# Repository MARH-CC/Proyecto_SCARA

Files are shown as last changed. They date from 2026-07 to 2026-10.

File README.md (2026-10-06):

# Proyecto SCARA – Universidad Militar Nueva Granada

Este repositorio contiene el desarrollo completo de un robot manipulador tipo **SCARA**, desde el diseño mecánico en SolidWorks hasta su modelado cinemático, su simulación en Matlab, su descripción en formato URDF y la sintonización del control de posición de sus servomotores. El objetivo del proyecto es diseñar, modelar y simular un brazo SCARA accionado por servomotores y una articulación prismática que permita una implementación precisa.

El robot tiene **3 grados de libertad**: dos articulaciones rotacionales ($\theta_1$, $\theta_2$) y una prismática ($d_3$).

## Estructura del repositorio

| Carpeta | Contenido |
|---|---|
| [`1. Piezas y Ensambles SolidWorks`](./1.%20Piezas%20y%20Ensambles%20SolidWorks) | Piezas individuales (`.SLDPRT`) y ensamblajes (`.SLDASM`) del robot en SolidWorks, con y sin servomotor. |
| [`2. Planos`](./2.%20Planos) | Planos técnicos (`.SLDDRW`) de las piezas y del ensamblaje general, más su versión en PDF. |
| [`3.Cinematica_Directa`](./3.Cinematica_Directa) | Desarrollo y cálculo de la cinemática directa del robot, resuelta por dos métodos independientes (Matrices de Transformación Homogénea y Denavit–Hartenberg) que se contrastan entre sí. |
| [`4.Cinematica_Inversa`](./4.Cinematica_Inversa) | Desarrollo y cálculo de la cinemática inversa del robot mediante desacoplamiento geométrico (ley de cosenos para $\theta_1,\theta_2$ y despeje directo para $d_3$). |
| [`5. Matlab_Simscape`](./5.%20Matlab_Simscape) | Modelo y simulación del robot en Matlab/Simulink usando Simscape Multibody (cinemática directa e inversa animadas sobre el ensamble de SolidWorks) y [modelado del motor DC](./5.%20Matlab_Simscape/Modelado%20Motor%20DC/README.md) en Simscape. |
| [`6. Matlab_PeterCorke`](./6.%20Matlab_PeterCorke) | Cinemática inversa paso a paso y su verificación con el Robotics Toolbox de Peter Corke para Matlab (modelo DH con `SerialLink` y `fkine`). |
| [`7. URDF`](./7.%20URDF) | Descripción del robot en formato URDF exportada desde SolidWorks (complemento SW2URDF), con scripts en Python (yourdfpy y PyBullet) para visualizarla, moverla y validarla contra la cinemática. |
| [`8.Control_Motor`](./8.Control_Motor) | Sintonización del controlador de posición del servomotor: reglas de la literatura (modelo IPD), asignación de polos y método del relé, con la comparación de los cinco métodos. |

> 📌 Cada carpeta cuenta con su propio `README.md` explicando en detalle su contenido (las subcarpetas de `8.Control_Motor` también).

## Flujo del proyecto

```text
Diseño CAD (1, 2) ──► Cinemática analítica (3, 4) ──► Simulación y verificación (5, 6, 7) ──► Control del motor (8)
```

- Las **cinemáticas directa e inversa** (3 y 4) se contrastan con tres herramientas independientes: Simscape Multibody (5), el toolbox de Peter Corke (6) y el modelo URDF (7).
- La carpeta 8 retoma el modelado del motor DC de la carpeta 5, con los parámetros del servomotor del proyecto, y sintoniza el controlador de posición de cada articulación.

## Estado del proyecto

- [x] Diseño CAD de piezas y ensamblajes
- [x] Planos técnicos
- [x] Cinemática directa
- [x] Cinemática inversa
- [x] Simulación en Matlab (Simscape y Peter Corke)
- [x] Descripción URDF
- [x] Modelado y sintonización del control de los motores

## Requisitos

- **SolidWorks** (para abrir y editar los archivos `.SLDPRT` / `.SLDASM` / `.SLDDRW`), con los complementos *Simscape Multibody Link* y *SW2URDF* (instalador en `7. URDF/Exporter`) si se quiere exportar.
- **Matlab** con Simulink, Simscape (Multibody y Electrical) y Control System Toolbox, y el **Robotics Toolbox de Peter Corke** (`rvctools`, carpeta 6).
- **Python** con `yourdfpy`, `trimesh`, `pyglet` y `pybullet` para los scripts de la carpeta 7.
- **Git LFS**: los archivos pesados de SolidWorks y las mallas `.STL` están versionados con LFS (instalar `git lfs` antes de clonar).

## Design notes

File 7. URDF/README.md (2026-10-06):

# URDF del Robot SCARA

Esta carpeta contiene el **modelo URDF** del SCARA: una descripción del robot en formato XML (eslabones, articulaciones, ejes, límites, masas e inercias y mallas 3D) que se genera **directamente desde el ensamble de SolidWorks** con el complemento *SW2URDF* (SolidWorks to URDF Exporter).

Para qué sirve:

- Tener el robot en un formato estándar que entienden **ROS, Gazebo, PyBullet, yourdfpy**, etc.
- **Visualizar y mover** el robot real (con sus mallas) usando las variables articulares $\theta_1$, $\theta_2$ y $d_3$.
- **Validar** que el modelo de SolidWorks coincide con la cinemática calculada en las carpetas [3](../3.Cinematica_Directa/README.md), [4](../4.Cinematica_Inversa/README.md) y [6](../6.%20Matlab_PeterCorke/README.md).

El flujo completo es:

```text
Ensamble SolidWorks ──► SW2URDF ──► URDF + mallas STL ──► Python (yourdfpy / PyBullet) ──► comparación con la cinemática
```

---

## 0. Contenido de la carpeta

```text
7. URDF/
├── Exporter/                              Instalador y código del complemento SW2URDF
│   ├── sw2urdfSetup.exe
│   ├── solidworks_urdf_exporter-1.6.1.zip
│   └── solidworks_urdf_exporter-1.6.1.tar.gz
├── ArchivosURDF/                          Resultado de la exportación + scripts de prueba
│   ├── urdf/
│   │   ├── EnsamblajeFinal.SLDASM.urdf    ← el modelo del robot
│   │   └── EnsamblajeFinal.SLDASM.csv     Tabla de joints/links que genera el exportador
│   ├── meshes/                            Mallas 3D (STL) de cada eslabón
│   ├── config/  launch/  package.xml  CMakeLists.txt    Paquete ROS generado automáticamente
│   ├── export.log                         Registro del exportador
│   ├── URDF.py                            Visualizador (yourdfpy)
│   └── URDFMOV.py                         Simulador con sliders (PyBullet)
└── images/                                Capturas usadas en este documento
```

---

## 1. Instalación del exportador (`Exporter/`)

<div align="center">

| Archivo | Para qué sirve |
|---|---|
| `sw2urdfSetup.exe` | **Instalador** del complemento. Es el único que se necesita para exportar: se ejecuta con SolidWorks cerrado y deja instalado el add-in *SW2URDF*. |
| `solidworks_urdf_exporter-1.6.1.zip` / `.tar.gz` | **Código fuente** de la versión 1.6.1 (el mismo contenido empaquetado en dos formatos). Se guarda como respaldo por si se necesita recompilar o consultar cómo funciona. |

</div>

Después de instalar, hay que **activar el complemento** en SolidWorks: `Herramientas → Complementos…` y marcar **SW2URDF** (casilla de la izquierda para activarlo ahora, casilla *Iniciar* para que cargue siempre).

<p align="center">
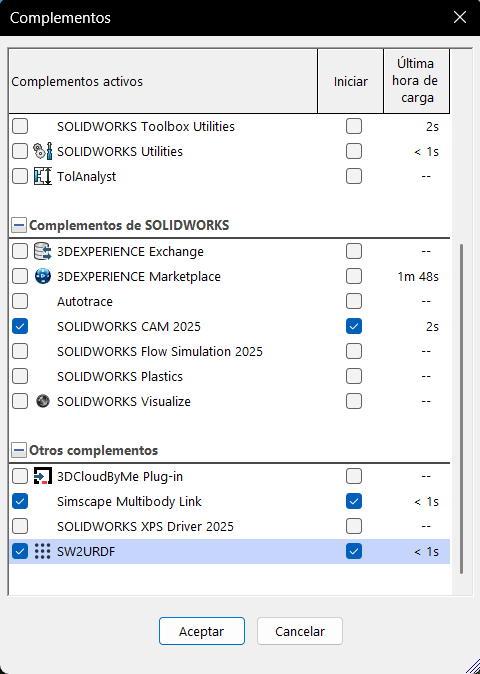
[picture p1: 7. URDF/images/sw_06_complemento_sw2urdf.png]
Ventana Complementos con SW2URDF activado
  
</p>

> El exportador lo mantiene la comunidad ROS: https://github.com/ros/solidworks_urdf_exporter

---

## 2. Preparar el ensamble en SolidWorks

El exportador **no adivina** dónde están las articulaciones: hay que dejarlas definidas con geometría de referencia en el ensamble. En `EnsamblajeFinal.SLDASM` se hizo así:

<p align="center">
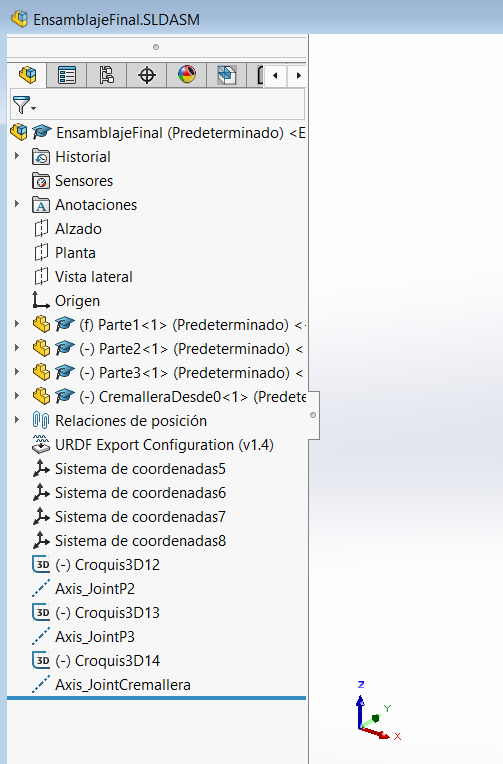
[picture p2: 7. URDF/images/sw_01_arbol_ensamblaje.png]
Árbol del ensamble con sistemas de coordenadas y ejes
  
</p>

<div align="center">

| Elemento del árbol | Qué es |
|---|---|
| `(f) Parte1<1>` | Primer eslabón, **fijo** (`f`): es la base del robot y no se mueve. |
| `(-) Parte2<1>`, `(-) Parte3<1>`, `(-) CremalleraDesde0<1>` | Eslabones **móviles** (`-` = grados de libertad libres). |
| `Sistema de coordenadas5 … 8` | Un sistema de coordenadas por articulación. Define el **origen y la orientación** del joint. El 5 es el origen global de la base y el 8 es el de la cremallera; los otros dos corresponden a los joints P2 y P3. |
| `Axis_JointP2`, `Axis_JointP3`, `Axis_JointCremallera` | **Ejes de movimiento** de cada articulación (creados a partir de un croquis 3D: `Croquis3D12/13/14`). |
| `URDF Export Configuration (v1.4)` | Configuración que el propio exportador guarda en el ensamble para no tener que repetirla. |

</div>

> **Regla práctica:** si el sistema de coordenadas o el eje de un joint no existen antes de abrir el exportador, hay que cancelar, crearlos y volver a empezar. El exportador mismo lo advierte en su ventana de configuración.

---

## 3. Exportar paso a paso

### Paso 1 — Abrir el exportador

Con el ensamble abierto: `Herramientas → Tools → Export as URDF`.

<p align="center">
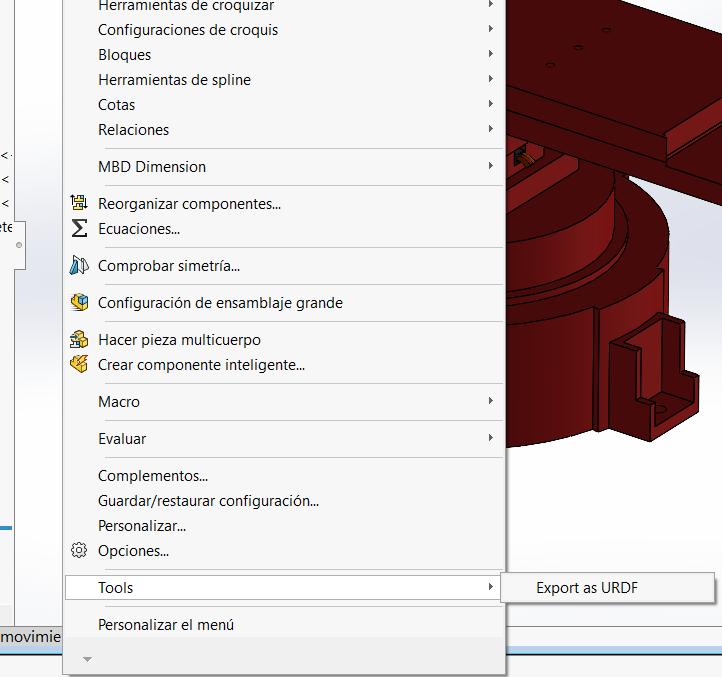
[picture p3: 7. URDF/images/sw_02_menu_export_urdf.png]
Menú Herramientas, submenú Tools, Export as URDF
  
</p>

### Paso 2 — Definir el link base

Se abre el *Property Manager* del exportador. Aquí se define el **primer link** (la base):

<p align="center">
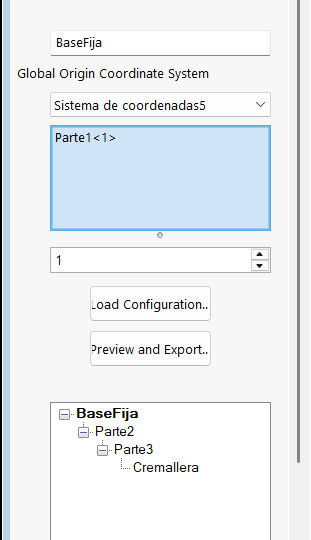
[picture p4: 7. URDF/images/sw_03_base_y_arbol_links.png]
Property Manager: link base BaseFija
  
</p>

- **Link Name:** `BaseFija`.
- **Global Origin Coordinate System:** `Sistema de coordenadas5` (el origen del URDF).
- **Componentes del link:** `Parte1<1>`.
- En el árbol de abajo se ve la cadena que se irá armando: `BaseFija → Parte2 → Parte3 → Cremallera`.

### Paso 3 — Agregar los links hijos y sus joints

Para cada eslabón siguiente (`Parte2`, `Parte3`, `Cremallera`) se agrega un link hijo y se configura su **joint**:

<p align="center">
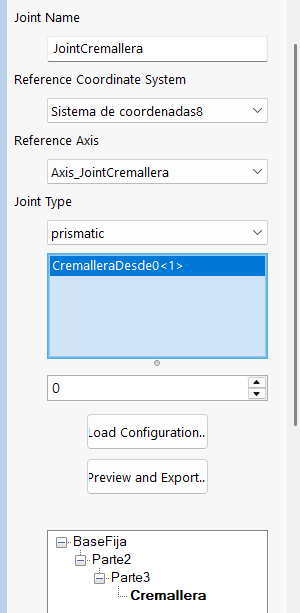
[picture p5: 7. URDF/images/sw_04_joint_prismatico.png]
Property Manager: JointCremallera, tipo prismatic
  
</p>

Ejemplo con la cremallera:

- **Joint Name:** `JointCremallera`.
- **Reference Coordinate System:** `Sistema de coordenadas8`.
- **Reference Axis:** `Axis_JointCremallera`.
- **Joint Type:** `prismatic`.
- **Componentes:** `CremalleraDesde0<1>`.

Los otros dos joints se configuran igual con sus propios sistemas y ejes (`JointP2` con `Axis_JointP2`, `JointP3` con `Axis_JointP3`), de tipo rotacional.

### Paso 4 — Revisar propiedades de cada joint

Con **Preview and Export…** aparece la ventana *Configure Joint Properties*, donde se revisa cada articulación del árbol (`JointP2 → JointP3 → JointCremallera`):

<p align="center">
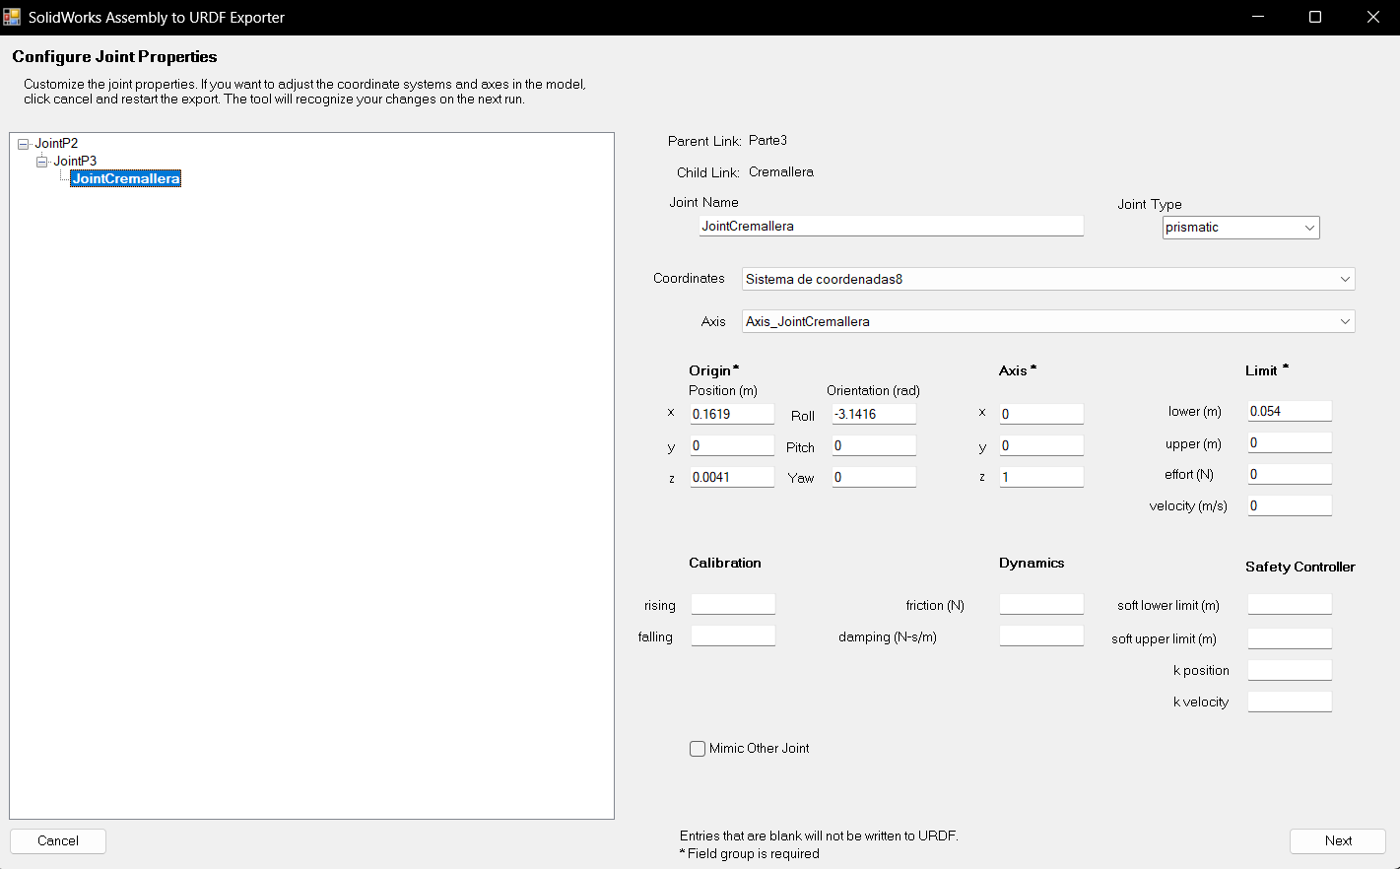
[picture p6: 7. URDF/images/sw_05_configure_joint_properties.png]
Ventana Configure Joint Properties para JointCremallera
  
</p>

Qué significa cada bloque (ejemplo `JointCremallera`):

<div align="center">

| Campo | Valor | Significado |
|---|---|---|
| **Parent / Child Link** | `Parte3` / `Cremallera` | Quién arrastra a quién. |
| **Origin – Position (m)** | $x=0.1619,\ y=0,\ z=0.0041$ | Dónde está el joint respecto al link padre: $l_2$ en $x$ y $h_3$ en $z$. |
| **Origin – Orientation (rad)** | Roll $=-3.1416$ | Giro de $-\pi$ alrededor de $x$: deja el eje $z$ de la cremallera apuntando **hacia abajo** (ver sección 5.2). |
| **Axis** | $(0,\ 0,\ 1)$ | Eje de movimiento, en el sistema del joint. |
| **Limit** | lower / upper, effort, velocity | Recorrido máximo y límites de fuerza y velocidad. |

</div>

> Los campos en blanco (calibración, dinámica, controlador de seguridad) **no se escriben** en el URDF.
>
> **Ajuste manual de límites:** en la ventana el exportador muestra `effort = 0` y `velocity = 0`. En el URDF final del repo están en `effort = 10`, `velocity = 0.1` y el recorrido es `lower = 0`, `upper = 0.054`: esos valores se editaron en el archivo `.urdf` después de exportar.

### Paso 5 — Exportar

Con **Next** se completa el asistente y se elige la carpeta de destino. El exportador genera el paquete completo (sección 4) y escribe el `export.log`.

---

## 4. Qué genera el exportador

<div align="center">

| Archivo / carpeta | Contenido |
|---|---|
| `urdf/EnsamblajeFinal.SLDASM.urdf` | **El modelo**: links, joints, masas e inercias. |
| `urdf/EnsamblajeFinal.SLDASM.csv` | Los mismos datos en tabla (sirve para volver a cargar la configuración con *Load Configuration…*). |
| `meshes/*.STL` | Una malla por link: `BaseFija`, `Parte2`, `Parte3`, `Cremallera`. Cada una está expresada en el **sistema de coordenadas de su link**. |
| `package.xml`, `CMakeLists.txt`, `launch/`, `config/` | Esqueleto de paquete ROS (catkin) para usarlo con `roslaunch`. |
| `export.log` | Registro de todo lo que hizo el exportador (útil si algo falla). |

</div>

Las rutas de las mallas dentro del URDF aparecen como `package://EnsamblajeFinal.SLDASM/meshes/…`. Esa sintaxis es la de ROS; fuera de ROS hay que traducirla a una ruta local (lo hacen los scripts de la sección 6).

> `launch/display.launch` espera un archivo `urdf.rviz` que el exportador no genera. Si se quiere usar con ROS/RViz, hay que crearlo.

---

## 5. Anatomía del URDF

El URDF se lee de forma muy parecida a la tabla DH: **un `link` por eslabón** y **un `joint` entre cada par**. Todas las unidades están en **metros y radianes** (la tabla DH de las otras carpetas está en cm).

### 5.1 Links

<div align="center">

| Link | Mesh | Masa [kg] | Rol |
|---|---|---|---|
| `BaseFija` | `BaseFija.STL` | 1.2446 | Base fija |
| `Parte2` | `Parte2.STL` | 0.24392 | Eslabón 1 ($l_1$) |
| `Parte3` | `Parte3.STL` | 0.23017 | Eslabón 2 ($l_2$) |
| `Cremallera` | `Cremallera.STL` | 0.059831 | Eje prismático (sube y baja) |

</div>

Cada link trae también su **centro de masa** y su **tensor de inercia** (calculados por SolidWorks), necesarios si se quiere simular dinámica.

### 5.2 Joints y relación con la tabla DH

```xml
<joint name="JointP2" type="continuous">
  <origin xyz="0.01054 0 0.1257" rpy="0 0 0" />
  <parent link="BaseFija" /> <child link="Parte2" />
  <axis xyz="0 0 1" />
</joint>
<joint name="JointP3" type="continuous">
  <origin xyz="0.15554 -1.5201E-05 0.0087" rpy="0 0 0" />
  <parent link="Parte2" /> <child link="Parte3" />
  <axis xyz="0 0 1" />
</joint>
<joint name="JointCremallera" type="prismatic">
  <origin xyz="0.1619 0 0.0041" rpy="-3.1416 0 0" />
  <parent link="Parte3" /> <child link="Cremallera" />
  <axis xyz="0 0 1" />
  <limit lower="0" upper="0.054" effort="10" velocity="0.1" />
</joint>
```

<div align="center">

| Joint | Tipo | `origin xyz` [m] | Equivale a | Variable |
|---|---|---|---|---|
| `JointP2` | continuo (sin límites) | $(0.01054,\ 0,\ 0.1257)$ | $(r_1,\ 0,\ h_1)$ | $\theta_1$ |
| `JointP3` | continuo (sin límites) | $(0.15554,\ \approx 0,\ 0.0087)$ | $(l_1,\ 0,\ h_2)$ | $\theta_2$ |
| `JointCremallera` | prismático, $0 \ldots 0.054$ m | $(0.1619,\ 0,\ 0.0041)$ | $(l_2,\ 0,\ h_3)$ | $d_3$ |

</div>

Los desplazamientos de `origin` son exactamente los parámetros de la cinemática directa ($r_1=1.054$, $h_1=12.57$, $l_1=15.554$, $h_2=0.87$, $l_2=16.190$, $h_3=0.41$ cm), así que el modelo de SolidWorks y el modelo DH describen **el mismo robot**.

Dos detalles importantes:

1. **El giro de $-\pi$ en `JointCremallera`** (`rpy="-3.1416 0 0"`) es el equivalente URDF del $\alpha_3=\pi$ de la tabla DH: invierte el eje $z$ de la cremallera para que apunte hacia abajo. Por eso un valor **positivo** del joint prismático **baja** el efector, igual que $d_3$ positivo en la DH ($p_z = h_1+h_2+h_3-h_4-d_3$). Resultado: **la variable del joint es directamente $d_3$**.
2. **El origen del link `Cremallera` no es la punta.** Coincide con el sistema $\lbrace 3\rbrace$ de la DH desplazado $d_3$. La punta (efector, sistema $\lbrace 4\rbrace$) está $h_4=5.40$ cm más abajo **sobre el eje $z$ de ese link**:

$$p_{\text{efector}} = p_{\text{origen del link}} + R_{\text{link}} \cdot \begin{bmatrix}0\\0\\h_4\end{bmatrix}$$

### 5.3 Vector de joints

El orden de los joints en el URDF es el mismo que el de las otras carpetas:

$$q = [\theta_1,\ \theta_2,\ d_3] = [\texttt{JointP2},\ \texttt{JointP3},\ \texttt{JointCremallera}]$$

Es decir, **los mismos valores** que se pasan a `BASETRASL` en MATLAB (carpeta 6) se pueden pasar al URDF (con $\theta$ en rad y $d_3$ en **metros**).

---

## 6. Validación en Python

Instalar las librerías (una vez):

```bash
pip install yourdfpy trimesh pyglet pybullet
```

Los dos scripts usan **rutas relativas**: se pueden ejecutar desde cualquier carpeta después de clonar el repositorio.

### 6.1 `URDF.py` — visor con yourdfpy

```bash
python URDF.py
```

Carga el URDF (traduciendo `package://…` a `meshes/…`), imprime los links y joints con su tipo, eje y origen, y abre una ventana 3D con el robot.

### 6.2 `URDFMOV.py` — simulador con sliders (PyBullet)

```bash
python URDFMOV.py
```

Abre PyBullet con tres sliders:

<div align="center">

| Slider | Joint | Rango |
|---|---|---|
| `JointP2 (theta1)` | 0 | −π … π rad |
| `JointP3 (theta2)` | 1 | −π … π rad |
| `JointCremallera (d3)` | 2 | 0 … 0.054 m |

</div>

En la consola se imprime en tiempo real $\theta_1$, $\theta_2$, $d_3$ y la **posición de la punta** $(X, Y, Z)$ en cm, calculada con la fórmula de la sección 5.2 (origen del frame del link + $h_4$ a lo largo de su eje $z$).

> PyBullet no entiende `package://`. El script resuelve eso creando una **copia temporal** del URDF con las rutas de mallas apuntando a esta carpeta; el URDF original no se modifica.

### 6.3 Poses de prueba

Se cargaron los ángulos de la cinemática inversa de la [carpeta 6](../6.%20Matlab_PeterCorke/README.md) en el URDF:

<div align="center">

| Pose | $q = [\theta_1,\ \theta_2,\ d_3]$ | Punta en el URDF [cm] | Punto de la inversa [cm] |
|---|---|---|---|
| **A** — brazo estirado | $[0°,\ 0°,\ 0]$ | $(32.798,\ -0.002,\ 8.450)$ | $(32.798,\ 0,\ 8.450)$ |
| **B** — codo $\theta_2>0$ | $[37.0°,\ 49.0°,\ 0]$ | $(14.606,\ 25.510,\ 8.450)$ | $(14.605,\ 25.511,\ 8.450)$ |
| **B** — codo $\theta_2<0$ | $[87.05°,\ -49.0°,\ 0]$ | $(14.607,\ 25.511,\ 8.450)$ | $(14.605,\ 25.511,\ 8.450)$ |
| **B** — con $d_3=5.4$ cm | $[37.0°,\ 49.0°,\ 0.054]$ | $(14.606,\ 25.510,\ 3.050)$ | — |

</div>

Las diferencias son **menores a 0.002 cm (0.02 mm)** y vienen del redondeo de los ángulos y del valor $-1.52\times10^{-5}$ m en la coordenada $y$ de `JointP3` en el URDF. Es decir: el modelo de SolidWorks exportado, la cinemática directa, la inversa y el toolbox de Peter Corke **coinciden**. La última fila confirma que con $d_3=5.4$ cm la punta baja de $8.45$ a $3.05$ cm.

<div align="center">

| Pose B — vista isométrica | Pose B — vista superior |
|---|---|
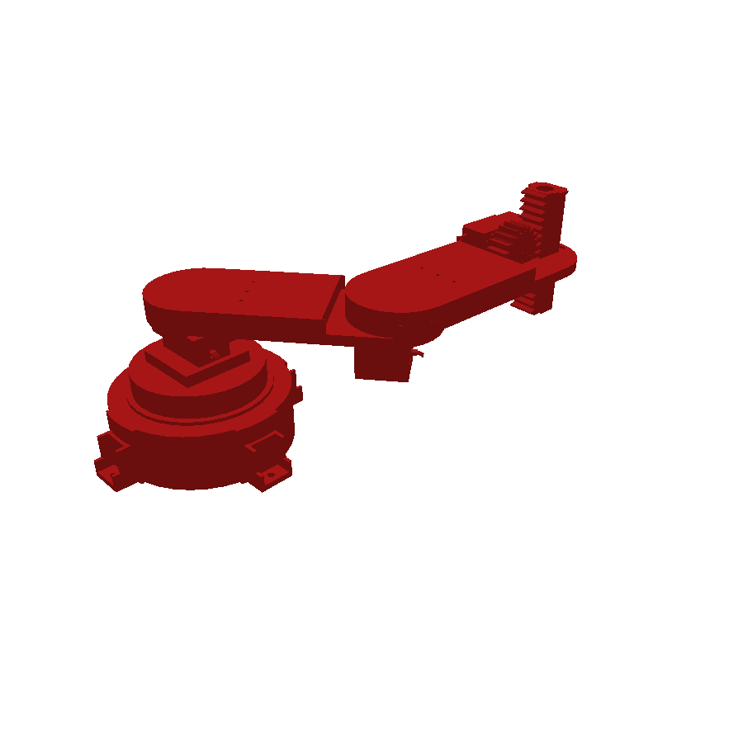
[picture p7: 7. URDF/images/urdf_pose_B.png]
Pose B del robot en el URDF
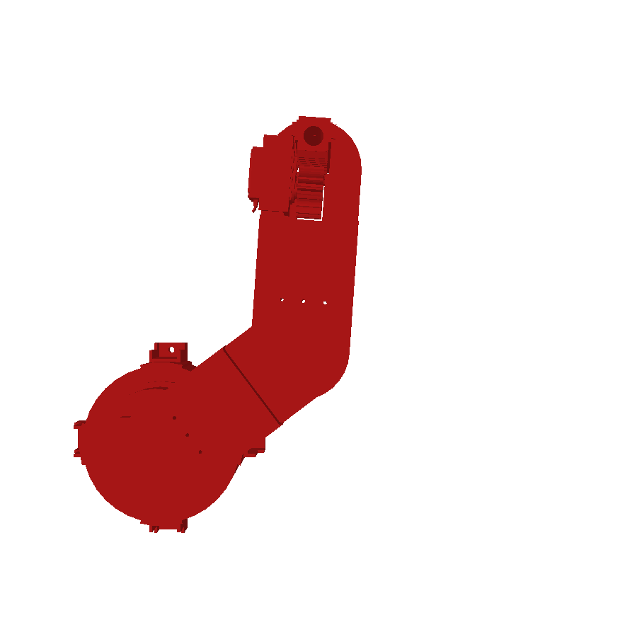
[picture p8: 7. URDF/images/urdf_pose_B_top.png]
Pose B vista superior
|  |  |

| Pose B con $d_3=5.4$ cm | Pose con todos los joints en 0 |
|---|---|
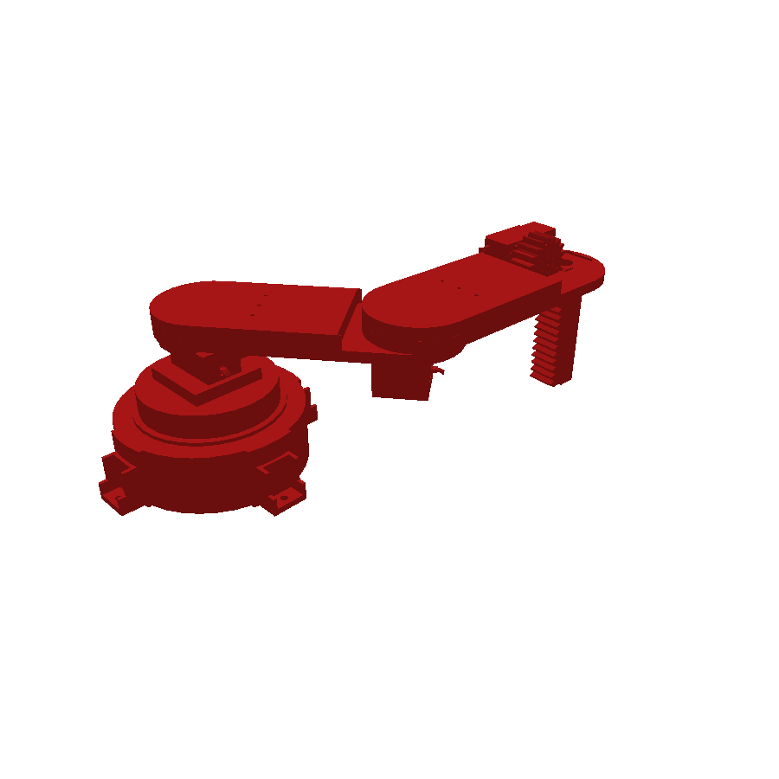
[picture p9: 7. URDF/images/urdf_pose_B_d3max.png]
Pose B con la prismática extendida
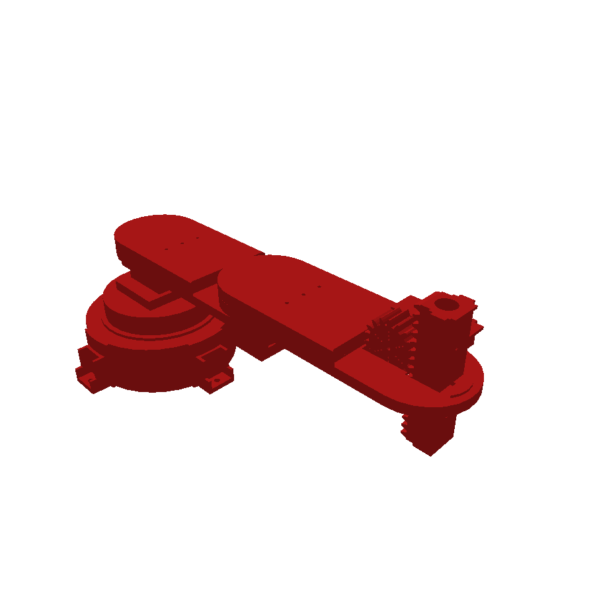
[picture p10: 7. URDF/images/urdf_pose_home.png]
Pose con joints en cero
|  |  |

</div>

---

## 7. Notas y diferencias a tener en cuenta

1. **Joints rotacionales sin límites:** `JointP2` y `JointP3` salieron como `continuous`. Si el mecanismo real tiene topes, se pueden cambiar a `revolute` y agregar `<limit lower=… upper=… />`.
2. **Posición del efector en PyBullet:** `getLinkState(...)[0]` devuelve el **centro de masa** del link y no el origen de su frame. Por eso `URDFMOV.py` usa los índices 4 y 5 (frame del link) y suma $h_4$.
3. **Versión anterior del URDF:** el primer URDF del repo (18-jun) usaba los nombres `Parte1` y `JointC`. Esta versión (exportación del 9-jul) renombra la base a `BaseFija` y el joint a `JointCremallera`, corrige la orientación de la prismática (giro de −π) y el sentido de su recorrido (de −0.054…0 a 0…0.054, de modo que el joint sea directamente $d_3$). El historial de git conserva la versión anterior.
4. **Unidades:** URDF en **m**, DH y MATLAB en **cm**.

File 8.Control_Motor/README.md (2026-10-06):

# Control de Posición del Servomotor del SCARA

Esta carpeta reúne el trabajo de **sintonización del controlador de posición** del servomotor que mueve cada articulación rotacional del SCARA (motor DC con reductor). El objetivo es llegar a un PI/PID (o P) que siga una referencia de ángulo con **poco sobreimpulso y tiempo de asentamiento corto**.

Para lograrlo se compararon **cinco métodos de sintonización** sobre la misma planta:

<div align="center">

| # | Método | Subcarpeta |
|---|---|---|
| 1 | Reglas de **literatura** para el modelo IPD — Leonard (1994) | [`SintonizacionLiteratura`](./SintonizacionLiteratura/README.md) |
| 2 | Reglas de **literatura** para el modelo IPD — Cluett y Wang (1997) | [`SintonizacionLiteratura`](./SintonizacionLiteratura/README.md) |
| 3 | Reglas de **literatura** para el modelo IPD — Åström y Hägglund (2006) | [`SintonizacionLiteratura`](./SintonizacionLiteratura/README.md) |
| 4 | **Asignación de polos** (diseño analítico PI y PID) | [`Asignacion_Polos`](./Asignacion_Polos/README.md) |
| 5 | **Método del relé** (ciclo último) con reglas Ziegler–Nichols, Smith, Tan y Corripio | [`Metodo_Rele`](./Metodo_Rele/README.md) |

</div>

Cada subcarpeta tiene su propio README con el procedimiento completo; este documento es la **visión general y la comparación final**.

---

## 0. Contenido de la carpeta

```text
8.Control_Motor/
├── README.md                          Este documento
├── ComparacionMetodos.slx             Modelo Simulink que compara los 5 métodos con la misma referencia
├── Analisis5Metodos.xlsx              Sobrepico y Ts observados por salto y por método
├── GraficarFiguras.m                  Script que reproduce las figuras de los README (Control System Toolbox)
├── images/
├── SintonizacionLiteratura/           Caracterización del motor (modelo IPD) + reglas del Handbook de O'Dwyer
│   ├── ControladoresLibro.slx
│   └── README.md
├── Asignacion_Polos/                  Diseño PI y PID por asignación de polos
│   ├── AsignacionPolos.slx
│   └── README.md
└── Metodo_Rele/                       Experimento del relé con histéresis + 4 familias de reglas
    ├── MetodoRele.slx
    ├── Sintonizacion_Rele.xlsx
    └── README.md
```

---

## 1. La planta

Todos los métodos se aplican sobre el **mismo modelo del motor**, construido en Simscape (circuito de armadura + convertidor electromecánico + inercia + amortiguamiento + reductor), igual que en [`5. Matlab_Simscape/Modelado Motor DC`](../5.%20Matlab_Simscape/Modelado%20Motor%20DC/README.md) pero con los parámetros del servomotor del proyecto:

<div align="center">

| Parámetro | Valor |
|---|---|
| Resistencia de armadura $R$ | $2.5\ \Omega$ |
| Inductancia de armadura $L$ | $1\ \text{mH}$ |
| Constante del motor $K=K_a=K_m$ | $5.8857\times10^{-3}\ \text{V·s/rad}$ |
| Inercia del rotor $J_m$ | $6.3173\times10^{-7}\ \text{kg·m}^2$ |
| Fricción viscosa $\beta$ (`Dm`) | $2.5\times10^{-7}\ \text{N·m·s/rad}$ |
| Reductor $N$ | $275.6923:1$ |
| Inercia de la carga $J_l$ | $2\times10^{-6}\ \text{kg·m}^2$ |

</div>

Linealizando este modelo (voltaje de armadura → posición angular **a la salida del reductor**) se obtiene la función de transferencia que se usa en todos los lazos:

$$
G(s)=\frac{\theta(s)}{V(s)}=\frac{33792}{s^3+2500\,s^2+55822\,s}=\frac{33792}{s\,(s+22.5)(s+2477.5)}
$$

Esta función sale de la misma expresión de la carpeta de modelado del motor, $\theta/V = K\big/\big(N\,s\,[(Ls+R)(Js+\beta)+K^2]\big)$, con $J=J_m+J_l/N^2$. Evaluada con los parámetros de arriba da $33792.8\,/\,(s^3+2500.4\,s^2+55822.9\,s)$, es decir, la de los modelos.

Sus polos son:

<div align="center">

| Polo | Valor | Origen |
|---|---|---|
| $s=0$ | $0$ | Integrador: velocidad → posición |
| $s_1$ | $-22.5$ | Polo mecánico (el dominante) |
| $s_2$ | $-2477.5$ | Polo eléctrico ($\approx R/L=2500$) |

</div>

Como la planta ya tiene un integrador, es de **tipo 1**: cualquier controlador estable la lleva a **error nulo ante un escalón** de referencia.

### Aproximación por modelo IPD

Para aplicar las reglas del Handbook, la planta se aproxima por un **integrador más retardo (IPD)**:

$$
G_m(s)=\frac{K_m\,e^{-s\,\tau_m}}{s}\qquad K_m\approx 0.61\ \tfrac{\text{rad/s}}{\text{V}},\quad \tau_m = 0.0464\ \text{s}
$$

Los parámetros $K_m$ y $\tau_m$ se obtuvieron de **ensayos al escalón** (1 V, 2.5 V y 5 V); el procedimiento está en [`SintonizacionLiteratura`](./SintonizacionLiteratura/README.md).

---

## 2. Referencia usada para comparar

Para probar los controladores con distintas amplitudes en una sola simulación se usa una **escalera de 10 saltos acumulados** (bloques `Step` del modelo `ComparacionMetodos.slx`):

<div align="center">

| Salto | Tiempo [s] | Incremento $\Delta r$ [°] | Incremento [rad] | Nivel final [°] |
|:-:|:-:|:-:|:-:|:-:|
| 1 | 1 | 0.1 | 0.0017453 | 0.1 |
| 2 | 4 | 1 | 0.0174533 | 1.1 |
| 3 | 15 | 5 | 0.0872665 | 6.1 |
| 4 | 26 | 10 | 0.1745329 | 16.1 |
| 5 | 38 | 20 | 0.3490659 | 36.1 |
| 6 | 48 | 30 | 0.5235988 | 66.1 |
| 7 | 58 | 45 | 0.7853982 | 111.1 |
| 8 | 68 | 60 | 1.0471976 | 171.1 |
| 9 | 78 | 90 | 1.5707963 | 261.1 |
| 10 | 88 | 130 | 2.268928 | 391.1 |

</div>

El sobrepico de cada salto se calcula como

$$
\text{Sobrepico}\ [\%]=\frac{\text{pico observado}-\text{nivel objetivo}}{\Delta r}\times100
$$

---

## 3. Modelo de comparación

<p align="center">
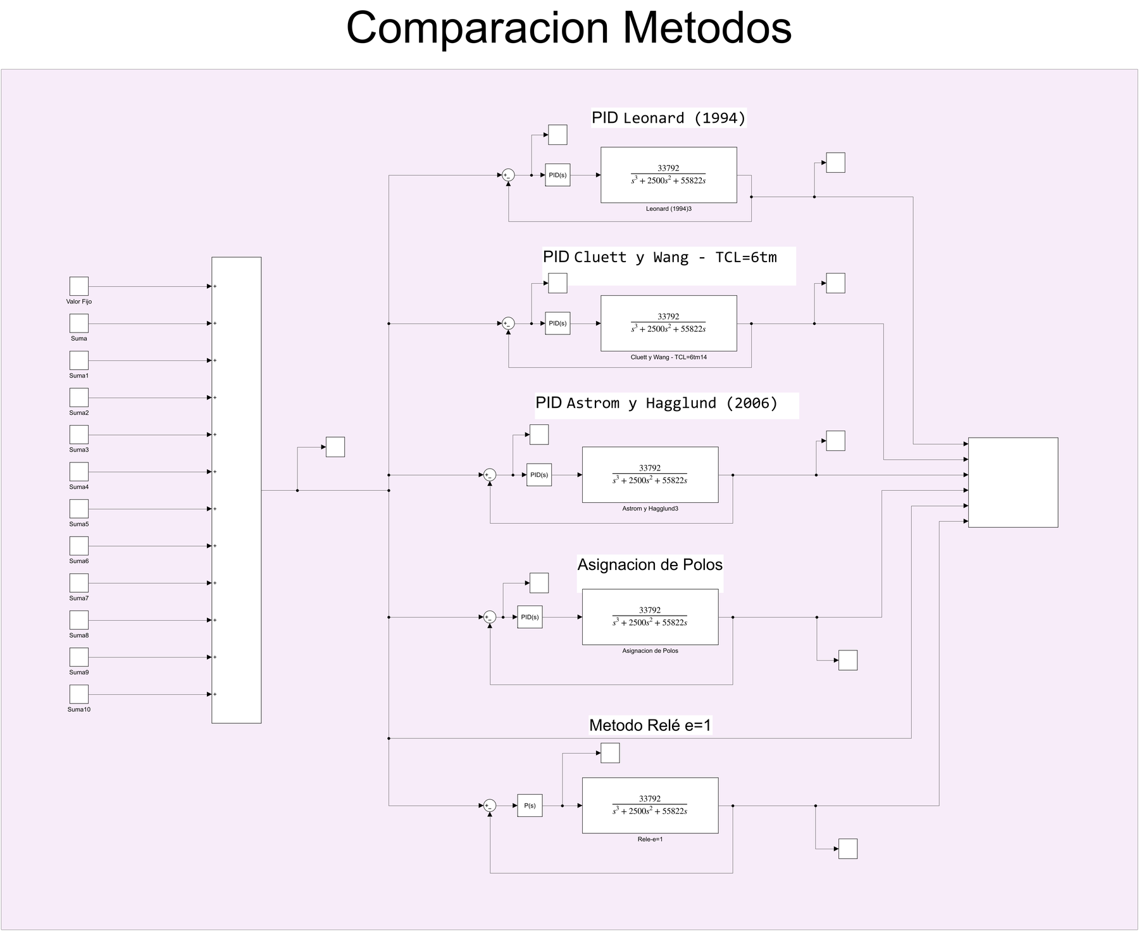
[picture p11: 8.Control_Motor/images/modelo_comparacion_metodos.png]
Modelo Simulink ComparacionMetodos
  
</p>

`ComparacionMetodos.slx` pone **los cinco lazos cerrados en paralelo**, todos con la misma planta $G(s)$ y la misma escalera de referencia:

<div align="center">

| Lazo | Controlador (bloque PID de Simulink) |
|---|---|
| PID Leonard (1994) | $K_p=26.1447,\ K_i=46.1855,\ K_d=0.4974$ |
| PID Cluett y Wang, $T_{CL}=6\tau_m$ | $K_p=9.5711,\ K_i=15.6962,\ K_d=0.0564$ |
| PID Åström y Hägglund (2006) | $K_p=15.8988,\ K_i=42.8309,\ K_d=0.3689$ |
| Asignación de polos (PID) | $K_p=12.11,\ K_i=2.4,\ K_d=0.147$ (valores del bloque; el cálculo analítico da $12.12,\ 2.706,\ 0.148$) |
| Método del relé $\varepsilon=1$ (Z-N, **P**) | $K_p=10.817$ |

</div>

Todos los bloques usan filtro derivativo $N=100$. Los scopes y el `Mux` de la derecha agrupan las señales para compararlas.

---

## 4. Resultados

Valores leídos de los osciloscopios y registrados en [`Analisis5Metodos.xlsx`](./Analisis5Metodos.xlsx) (hoja *Resumen*). Cada celda es **sobrepico / tiempo de asentamiento**:

<div align="center">

| Salto | t [s] | Δr [°] | Leonard (1994) | Cluett y Wang ($T_{CL}=6\tau_m$) | Åström y Hägglund (2006) | Asignación de polos | Relé $\varepsilon=1$ (P) |
|:-:|:-:|:-:|:-:|:-:|:-:|:-:|:-:|
| 1 | 1 | 0.1 | 8.3 % / 0.90 s | 20.3 % / 1.40 s | 20.3 % / 0.90 s | 3.1 % / 9.2 s | 0.03 % / 0.5 s |
| 2 | 4 | 1.0 | 12.0 % / 1.7 s | 18.9 % / 2.2 s | 19.5 % / 1.4 s | 2.9 % / 9.29 s | 0.04 % / 0.5 s |
| 3 | 15 | 5.0 | 12.1 % / 2.1 s | 18.7 % / 2.25 s | 19.3 % / 1.5 s | 2.4 % / 12 s | 0.04 % / 0.6 s |
| 4 | 26 | 10.0 | 12.1 % / 2.5 s | 18.7 % / 2.5 s | 19.1 % / 1.6 s | 2.2 % / 12 s | 0.06 % / 0.6 s |
| 5 | 38 | 20.0 | 12.1 % / 2.7 s | 18.7 % / 2.7 s | 19.1 % / 1.6 s | 2.6 % / 12 s | 0.04 % / 0.6 s |
| 6 | 48 | 30.0 | 12.1 % / 2.7 s | 18.7 % / 2.7 s | 19.1 % / 1.6 s | 2.7 % / 13 s | 0.05 % / 0.65 s |
| 7 | 58 | 45.0 | 12.1 % / 2.7 s | 18.7 % / 2.7 s | 19.1 % / 1.6 s | 2.7 % / 13 s | 0.04 % / 0.65 s |
| 8 | 68 | 60.0 | 12.1 % / 2.8 s | 18.7 % / 2.8 s | 19.0 % / 1.7 s | 2.8 % / 14 s | 0.04 % / 0.7 s |
| 9 | 78 | 90.0 | 12.1 % / 2.8 s | 18.7 % / 2.8 s | 19.1 % / 1.7 s | 2.7 % / 14 s | 0.05 % / 0.7 s |
| 10 | 88 | 130.0 | 12.1 % / 2.8 s | 18.7 % / 2.8 s | 19.0 % / 1.7 s | 2.8 % / 14 s | 0.05 % / 0.7 s |

</div>

Resumen (saltos 2 a 10; el salto 1 queda afectado por la resolución de lectura, al ser de solo 0.1°):

<div align="center">

| Método | Sobrepico | Ts observado |
|---|:-:|:-:|
| Leonard (1994) | ≈ 12.1 % | 1.7 – 2.8 s |
| Cluett y Wang ($T_{CL}=6\tau_m$) | ≈ 18.7 % | 2.2 – 2.8 s |
| Åström y Hägglund (2006) | ≈ 19.1 % | 1.4 – 1.7 s |
| Asignación de polos | ≈ 2.7 % | 9.3 – 14 s |
| **Relé $\varepsilon=1$ (P)** | **≈ 0.05 %** | **0.5 – 0.7 s** |

</div>

<p align="center">
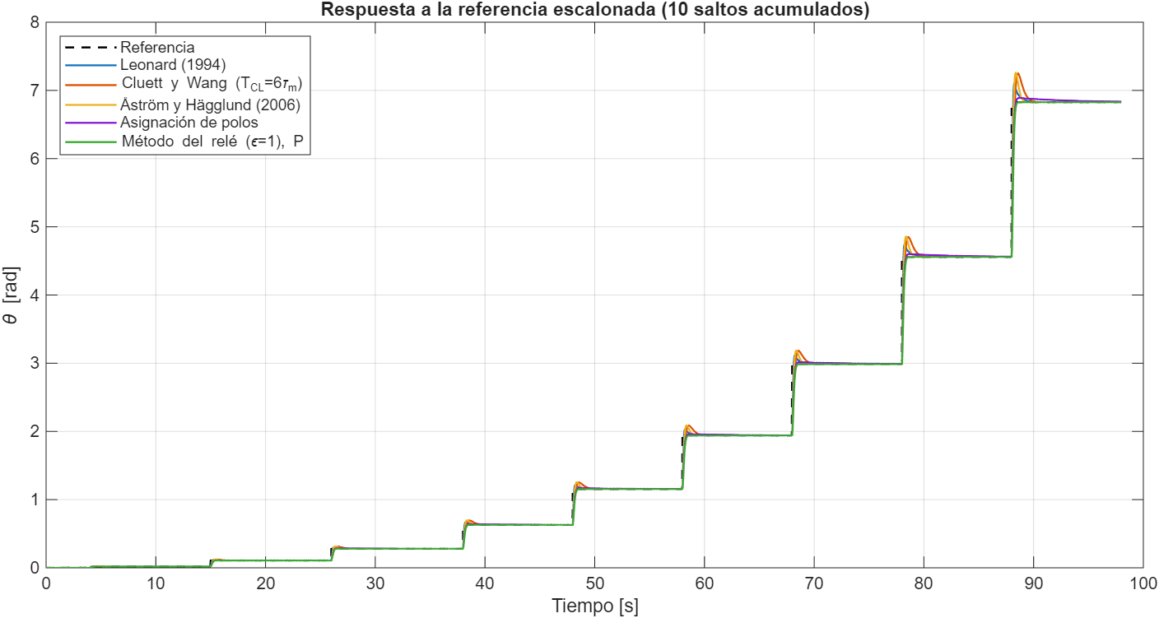
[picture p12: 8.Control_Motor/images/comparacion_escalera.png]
Respuesta de los cinco métodos a la escalera de referencia
  
</p>

<p align="center">
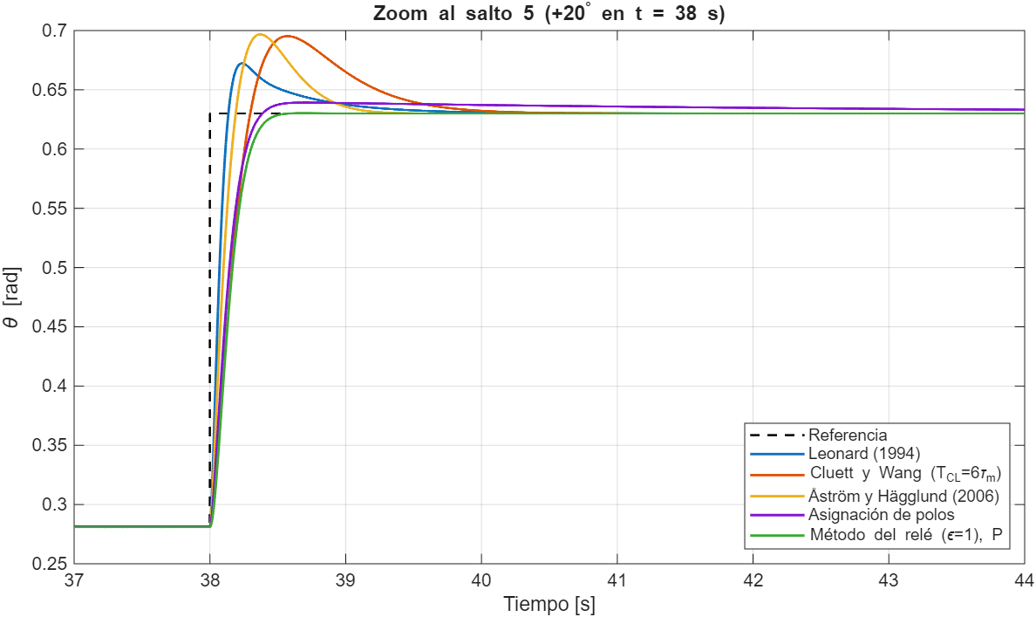
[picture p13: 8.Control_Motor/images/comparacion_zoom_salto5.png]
Zoom al salto 5
  
</p>

> Las dos figuras se generaron con `GraficarFiguras.m`, que reconstruye los cinco lazos con los $K_p$, $K_i$, $K_d$ guardados en los bloques PID de los modelos. Los **sobrepicos simulados coinciden con los del Excel** (Leonard 12.1 %, Cluett y Wang 18.7 %, Åström y Hägglund 19.1 %, asignación de polos 2.5–2.8 %, relé 0.05 %).

### Lectura de los resultados

- **Reglas de literatura (IPD):** responden rápido, pero con **12 – 19 % de sobrepico**. Son reglas pensadas para un compromiso general y no para un servo de posición.
- **Asignación de polos:** el sobrepico es bajo (≈ 2.7 %) y el **tiempo de subida cumple lo diseñado** (el PID llega al 98 % a los 0.34 s, contra los 0.33 s pedidos), pero queda una **cola lenta** (polo en ≈ −0.23, casi cancelado por un cero del controlador en ≈ −0.22) que alarga el Ts observado a 9–14 s. Detalle en su [README](./Asignacion_Polos/README.md).
- **Método del relé, $\varepsilon=1$, control P:** el mejor en ambos criterios (sobrepico ≈ 0.05 % y Ts ≈ 0.6 s). Funciona bien porque la planta ya tiene integrador, así que un P basta para error cero en escalón. El análisis de los 36 casos (6 histéresis × 6 reglas) está en [`Metodo_Rele`](./Metodo_Rele/README.md).

> **Nota sobre el Ts:** en el Excel el Ts crece con el tamaño del salto aunque el sistema es lineal; esto indica que el valor depende del criterio de lectura en el osciloscopio. Sirve para **comparar métodos entre sí**, no como valor absoluto.

---

## 5. Cómo reproducir

1. Abrir en MATLAB (con Simulink, Simscape y Simscape Electrical) el modelo que se quiera revisar: `ComparacionMetodos.slx`, `Asignacion_Polos/AsignacionPolos.slx`, `Metodo_Rele/MetodoRele.slx` o `SintonizacionLiteratura/ControladoresLibro.slx`.
2. Para regenerar las figuras de los README (necesita **Control System Toolbox**):

   ```matlab
   run('GraficarFiguras.m')
   ```

---

## 6. Observaciones

1. **Ganancias de asignación de polos.** El README de la subcarpeta usa las del cálculo analítico ($K_p=12.12$, $K_i=2.706$, $K_d=0.148$). Los modelos guardan valores un poco distintos ($K_i=2.5$ en `AsignacionPolos.slx` y $K_i=2.4$ en `ComparacionMetodos.slx`, de donde salen los resultados del Excel); el efecto en la respuesta es mínimo (sobrepico 2.5–2.8 %).
2. **Valores de la caracterización.** Los controladores se calcularon con $K_m=0.610$ y $\tau_m=0.0464$ s (el $K_m$ del ensayo de 2.5 V). Esto se comprobó recalculando los seis controladores: coinciden con los bloques PID hasta la cuarta cifra decimal.

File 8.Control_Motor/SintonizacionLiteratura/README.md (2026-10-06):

# Sintonización con Reglas de la Literatura (Modelo IPD)

En este método se **aprovechan reglas de sintonización ya publicadas**: se aproxima el motor por un modelo sencillo de dos parámetros, se buscan en el *Handbook of PI and PID Controller Tuning Rules* (A. O'Dwyer, Imperial College Press) las reglas disponibles para ese modelo y se calculan las ganancias con fórmulas cerradas.

El proceso tiene tres pasos:

1. **Caracterizar** el motor con ensayos al escalón y extraer los parámetros del modelo **IPD** (integrador más retardo): $K_m$ y $\tau_m$.
2. **Elegir reglas** del Handbook para ese modelo (capítulo 4, tablas de PI y PID) y calcular $K_p$, $T_i$, $T_d$.
3. **Probar** los controladores en Simulink con la planta del motor.

---

## 0. Contenido

<div align="center">

| Archivo | Descripción |
|---|---|
| `ControladoresLibro.slx` | Modelo Simulink: motor en Simscape para 1, 2.5 y 5 V, comparación contra el modelo IPD y los lazos con los mejores PI y PID |
| `images/` | Figuras de la caracterización y paneles del modelo |

</div>

---

## 1. Modelo de proceso: integrador más retardo (IPD)

El Handbook agrupa en el capítulo 4 las reglas para **procesos sin autorregulación** ("non-self-regulating"), es decir, procesos con integrador, que es el caso de un motor cuya salida es la **posición angular**. El modelo (sección *IPD model*) es:

$$
G_m(s)=\frac{K_m\,e^{-s\,\tau_m}}{s}
$$

con $K_m$ la **ganancia de velocidad** (rad/s por voltio) y $\tau_m$ el **retardo aparente**.

### 1.1 Cómo se obtienen $K_m$ y $\tau_m$

Se aplica un **escalón de voltaje** a la planta y se mide la respuesta de posición, que después de un pequeño transitorio es una **rampa**. Sobre la gráfica se leen los instantes y niveles:

<div align="center">

| Símbolo | Significado |
|---|---|
| $T_1$ | Instante en que se aplica el escalón |
| $T_2$ | Instante en que la recta de la rampa **corta el nivel inicial** de la salida |
| $T_3$ | Un instante cualquiera sobre la parte recta de la rampa |
| $I_1,\ I_2$ | Entrada antes y después del escalón |
| $O_1,\ O_2$ | Salida inicial y salida en $T_3$ |

</div>

$$
K_m=\frac{O_2-O_1}{(I_2-I_1)\,(T_3-T_2)}\qquad\qquad \tau_m=T_2-T_1
$$

La pendiente de la rampa dividida entre la amplitud del escalón es $K_m$, y el desfase de la rampa respecto al instante del escalón es el retardo $\tau_m$.

### 1.2 Ensayos realizados

El ensayo se hizo con el modelo Simscape del motor para **tres amplitudes de escalón: 1 V, 2.5 V y 5 V** (si el modelo fuera perfectamente lineal el resultado sería el mismo en los tres; las pequeñas diferencias vienen de la lectura de los instantes en el osciloscopio).

En cada ensayo el modelo pone en paralelo la salida del **motor en Simscape**, la **función de transferencia linealizada** $33792/(s^3+2500s^2+55822s)$ y el **modelo IPD** ($0.6075/s$ con un retardo de 0.0464 s):

<div align="center">

| 1 V | 2.5 V | 5 V |
|:-:|:-:|:-:|
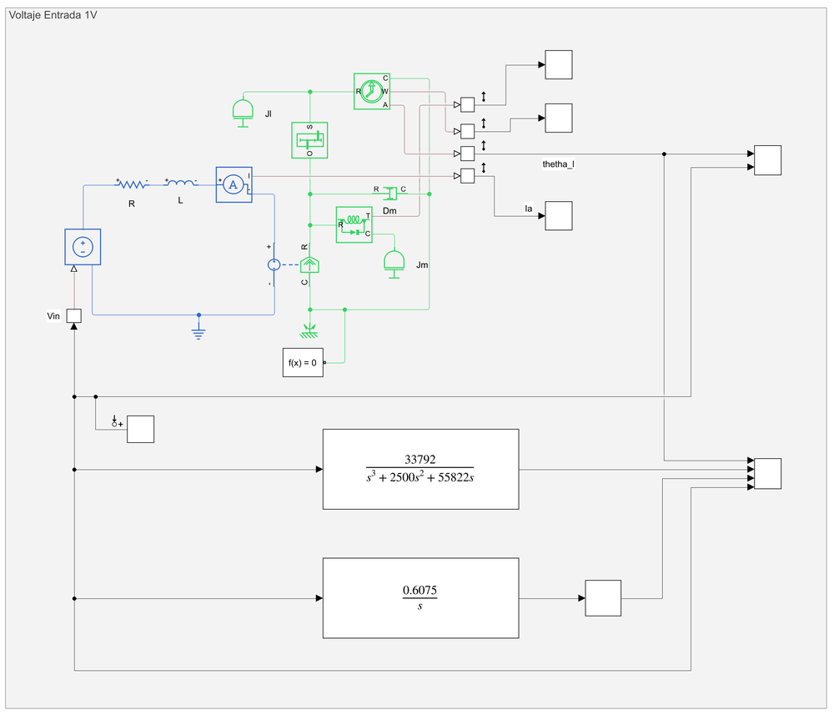
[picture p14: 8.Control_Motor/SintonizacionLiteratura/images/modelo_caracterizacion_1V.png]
Modelo de caracterización a 1 V
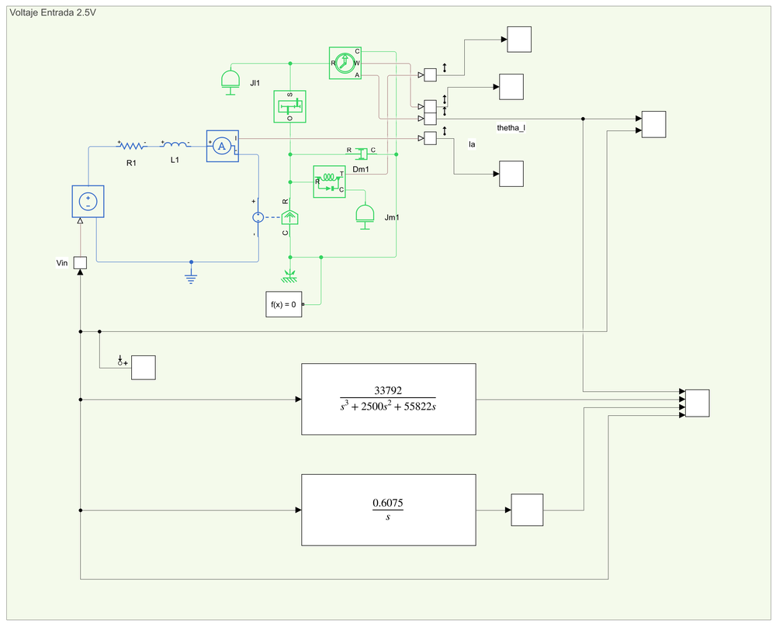
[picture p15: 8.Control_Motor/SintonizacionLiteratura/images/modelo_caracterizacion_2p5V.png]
Modelo de caracterización a 2.5 V
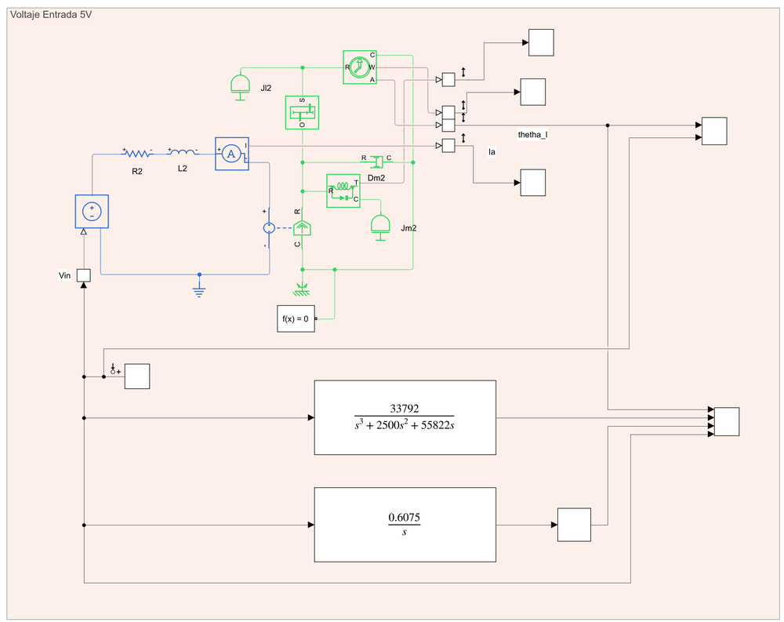
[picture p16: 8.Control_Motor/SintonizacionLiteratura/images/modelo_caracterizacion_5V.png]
Modelo de caracterización a 5 V
|  |  |  |

</div>

La respuesta de posición de la planta a cada escalón, con los instantes leídos ($T_1=1$ s, $T_2=1.0464$ s y $T_3$ sobre la rampa), la recta de la rampa y el punto $(T_3,\ O_2)$:

<p align="center">
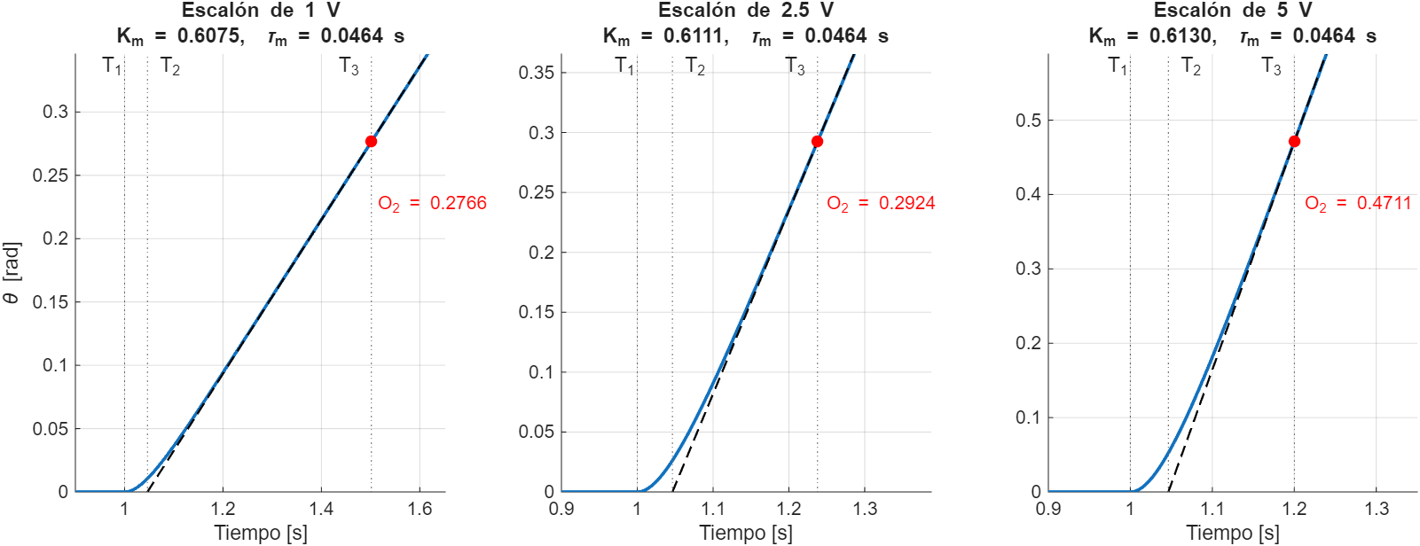
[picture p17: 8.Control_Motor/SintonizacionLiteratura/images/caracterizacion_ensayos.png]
Respuesta al escalón de 1, 2.5 y 5 V con la construcción de Km y tau_m
  
</p>

**Lecturas y resultados:**

<div align="center">

| Ensayo | $T_1$ [s] | $T_2$ [s] | $T_3$ [s] | $I_2$ | $O_2$ | $K_m$ | $\tau_m$ [s] |
|:-:|:-:|:-:|:-:|:-:|:-:|:-:|:-:|
| 1 V | 1 | 1.0464 | 1.5017 | 1 | 0.2766 | **0.6075** | 0.0464 |
| 2.5 V | 1 | 1.0464 | 1.2378 | 2.5 | 0.2924 | **0.6111** | 0.0464 |
| 5 V | 1 | 1.0464 | 1.2001 | 5 | 0.4711 | **0.6130** | 0.0464 |

</div>

En los tres casos $I_1=O_1=0$. Ejemplo (1 V):

$$
K_m=\frac{0.2766-0}{(1-0)(1.5017-1.0464)}=0.6075\qquad \tau_m=1.0464-1=0.0464\ \text{s}
$$

Los modelos IPD que resultan de cada ensayo son:

<div align="center">

| Ensayo | Modelo IPD |
|:-:|:-:|
| 1 V | $G_m(s)=\dfrac{0.6075\,e^{-0.0464\,s}}{s}$ |
| 2.5 V | $G_m(s)=\dfrac{0.6111\,e^{-0.0464\,s}}{s}$ |
| 5 V | $G_m(s)=\dfrac{0.6130\,e^{-0.0464\,s}}{s}$ |

</div>

### 1.3 Parámetros adoptados

Los tres valores de $K_m$ son muy parecidos (variación menor al 1 %); su promedio es 0.6105, así que se adoptó:

$$
\boxed{K_m=0.610\ \tfrac{\text{rad/s}}{\text{V}}\qquad\tau_m=0.0464\ \text{s}\qquad K_m\tau_m=0.028304}
$$

### 1.4 ¿Es razonable la aproximación?

Se puede comprobar contra la función de transferencia completa $G(s)=33792/\big(s(s+22.5)(s+2477.5)\big)$:

- **Ganancia:** a baja frecuencia la planta se comporta como un integrador de ganancia $33792/55822=0.605$ rad/s por voltio, que coincide con el $K_m$ medido (0.6075 – 0.613).
- **Retardo:** los dos polos no integradores se pueden aproximar por un retardo de $1/22.5+1/2477.5\approx0.045$ s, muy cerca del $\tau_m=0.0464$ s medido.

---

## 2. Reglas del Handbook utilizadas

Las reglas están en el **capítulo 4** del Handbook (*Controller Tuning Rules for Non-Self-Regulating Process Models*), sección 4.1 (modelo IPD): **Tabla 58** (PI, págs. 350–358 del libro) y **Tabla 59** (PID, págs. 359–363). En el PDF corresponden a las páginas 365–378.

> Las tablas del libro tienen decenas de reglas para este modelo. A continuación aparecen las que se llevaron a Simulink.

### 2.1 PI — Cluett y Wang (1997)

**Tabla 58, pág. 353.** Una familia de reglas parametrizada por el **tiempo de lazo cerrado deseado** $T_{CL}=x_4\,\tau_m$:

$$
K_c=\frac{x_1}{K_m\tau_m}\qquad T_i=x_2\,\tau_m
$$

<div align="center">

| $T_{CL}$ | $x_1$ | $x_2$ | $K_p$ | $T_i$ [s] | $K_i=K_p/T_i$ |
|:-:|:-:|:-:|:-:|:-:|:-:|
| $4\tau_m$ | 0.3752 | 9.1925 | 13.2561 | 0.4266 | 31.0787 |
| $5\tau_m$ | 0.3144 | 11.1637 | 11.1080 | 0.5180 | 21.4441 |
| $6\tau_m$ | 0.2709 | 13.1416 | 9.5711 | 0.6098 | 15.6962 |

</div>

Un $T_{CL}$ mayor da un controlador **más suave** (menor $K_p$, mayor $T_i$).

### 2.2 PID

**Tabla 59, págs. 360–362.** Controlador ideal $G_c(s)=K_c\big(1+1/(T_i s)+T_d s\big)$:

<div align="center">

| Regla | Tabla / pág. | $K_c$ | $T_i$ | $T_d$ | Comentario del libro |
|---|:-:|:-:|:-:|:-:|---|
| **Leonard (1994)** | 59 / 360 | $0.74/(K_m\tau_m)$ | $12.2\,\tau_m$ | $0.41\,\tau_m$ | Sobreimpulso < 10 % con escalón; mínimo IAE (rampa de perturbación) |
| **Cluett y Wang (1997)**, $T_{CL}=6\tau_m$ | 59 / 361 | $0.2709/(K_m\tau_m)$ | $13.1416\,\tau_m$ | $0.1269\,\tau_m$ | Familia con $T_{CL}=x_4\tau_m$ |
| **Åström y Hägglund (2006)**, págs. 263–264 | 59 / 362 | $0.45/(K_m\tau_m)$ | $8\,\tau_m$ | $0.5\,\tau_m$ | $M_s=M_t=1.4$ |

</div>

Ganancias resultantes (con $K_m\tau_m=0.028304$), en la forma paralela que usa el bloque PID de Simulink: $K_i=K_p/T_i$ y $K_d=K_p\,T_d$:

<div align="center">

| Regla | $K_p$ | $T_i$ [s] | $T_d$ [s] | $K_i$ | $K_d$ |
|---|:-:|:-:|:-:|:-:|:-:|
| Leonard (1994) | 26.1447 | 0.5661 | 0.01902 | 46.1855 | 0.4974 |
| Cluett y Wang ($6\tau_m$) | 9.5711 | 0.6098 | 0.00589 | 15.6962 | 0.0564 |
| Åström y Hägglund (2006) | 15.8988 | 0.3712 | 0.0232 | 42.8309 | 0.3689 |

</div>

Estos valores se **verificaron contra los bloques PID** de `ControladoresLibro.slx` y de `ComparacionMetodos.slx`: coinciden en $K_p$, $K_i$ y $K_d$ hasta la cuarta cifra decimal.

---

## 3. Modelo Simulink

`ControladoresLibro.slx` reúne en una sola hoja las tablas del Handbook (con flechas que marcan las reglas candidatas), los ensayos de caracterización y los lazos de prueba. Los lazos de prueba están organizados en **tres grupos de colores**, uno por cada amplitud del escalón de entrada (**1 V** gris, **2.5 V** verde, **5 V** rojo), y cada grupo tiene dos columnas:

- ***3 Best PI*:** los tres PI de Cluett y Wang con $T_{CL}=6\tau_m$, $5\tau_m$ y $4\tau_m$.
- ***3 Best PID*:** Leonard (1994), Cluett y Wang ($6\tau_m$) y Åström y Hägglund (2006).

En cada subsistema se compara la respuesta de la planta original (*Original Function*) con la del lazo cerrado con el controlador, en el mismo scope. Todos los bloques usan filtro derivativo $N=100$ y la planta $G(s)=33792/(s^3+2500s^2+55822s)$.

<div align="center">

| | **3 Best PI** | **3 Best PID** |
|:-:|:-:|:-:|
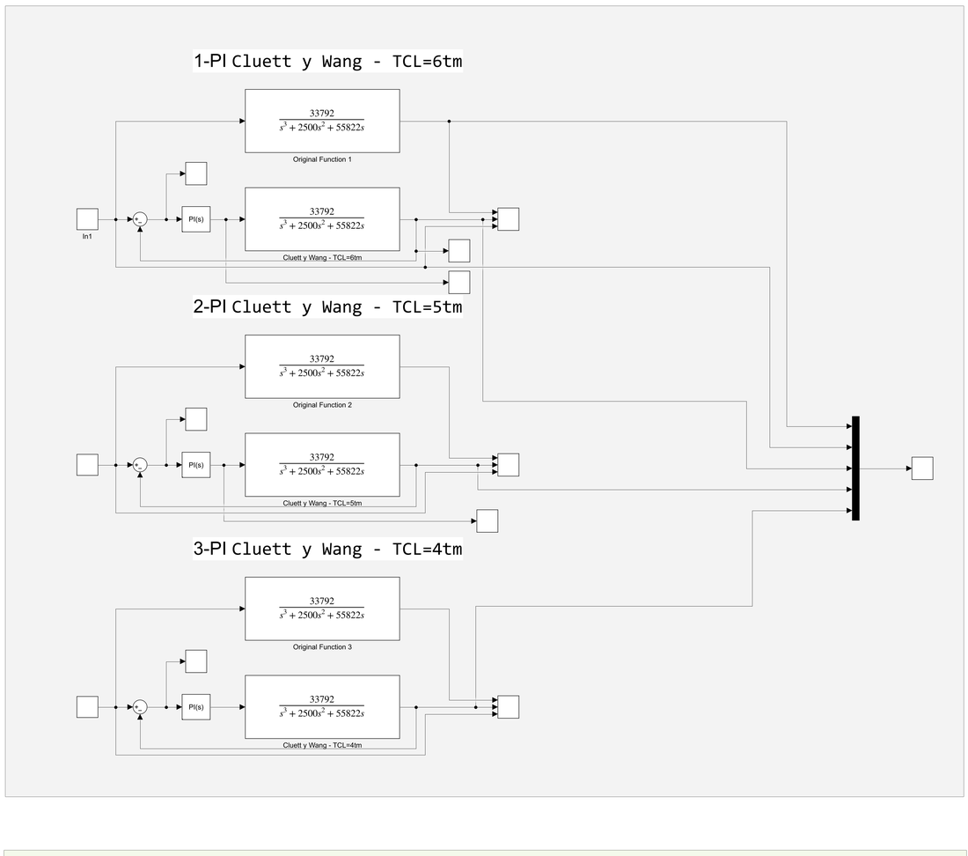
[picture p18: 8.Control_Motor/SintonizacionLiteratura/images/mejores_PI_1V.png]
3 mejores PI, 1 V
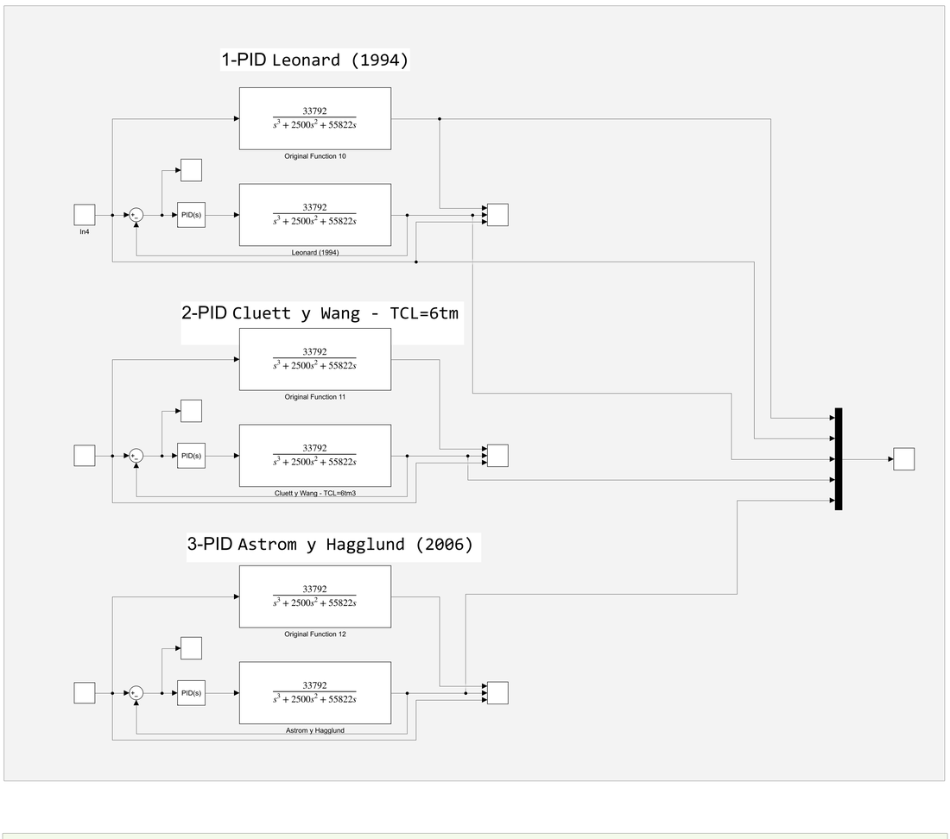
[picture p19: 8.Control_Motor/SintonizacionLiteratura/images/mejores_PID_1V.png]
3 mejores PID, 1 V
| **1 V** |  |  |
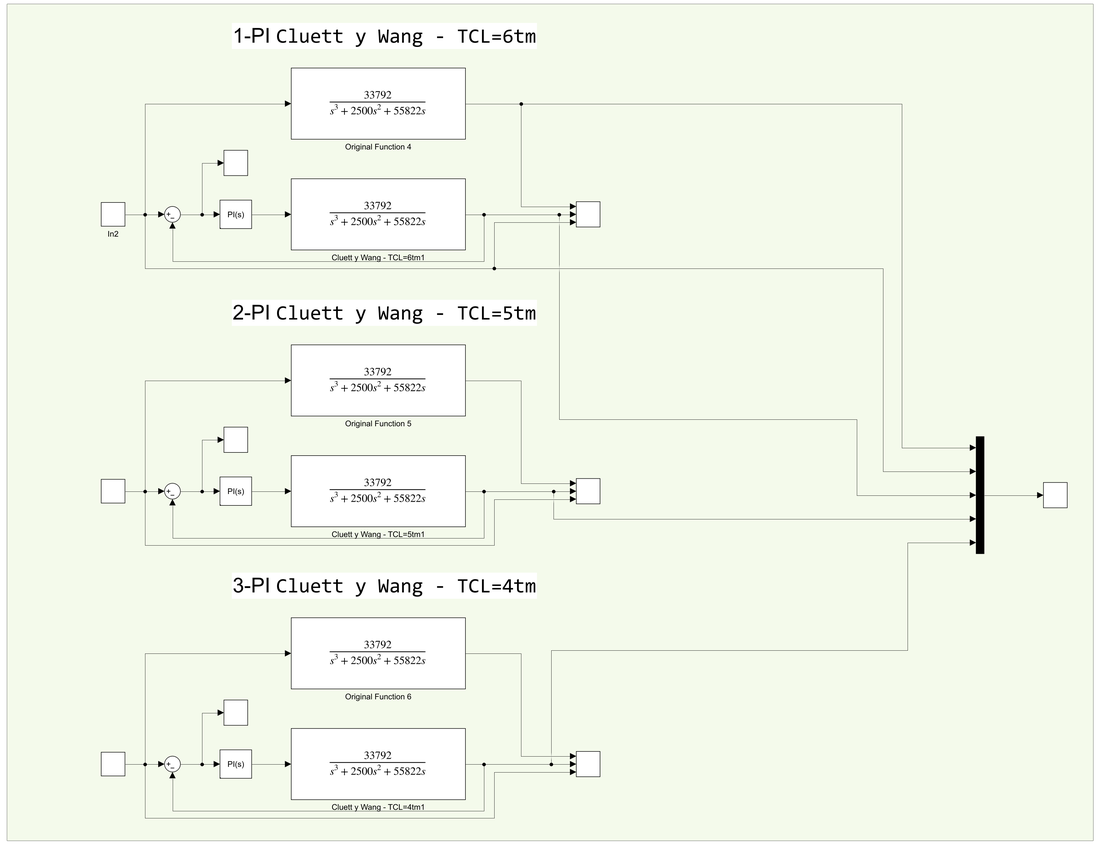
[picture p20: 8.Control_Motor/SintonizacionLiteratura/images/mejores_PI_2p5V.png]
3 mejores PI, 2.5 V
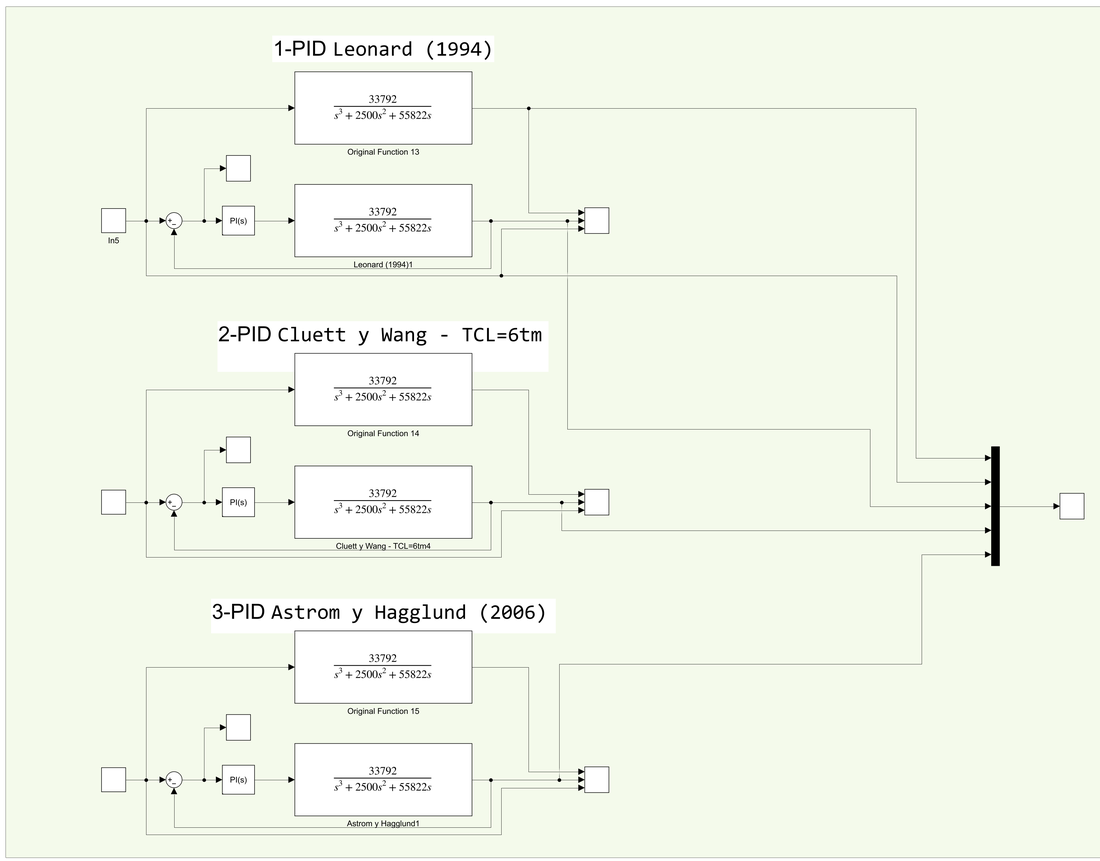
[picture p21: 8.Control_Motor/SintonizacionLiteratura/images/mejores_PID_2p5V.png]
3 mejores PID, 2.5 V
| **2.5 V** |  |  |
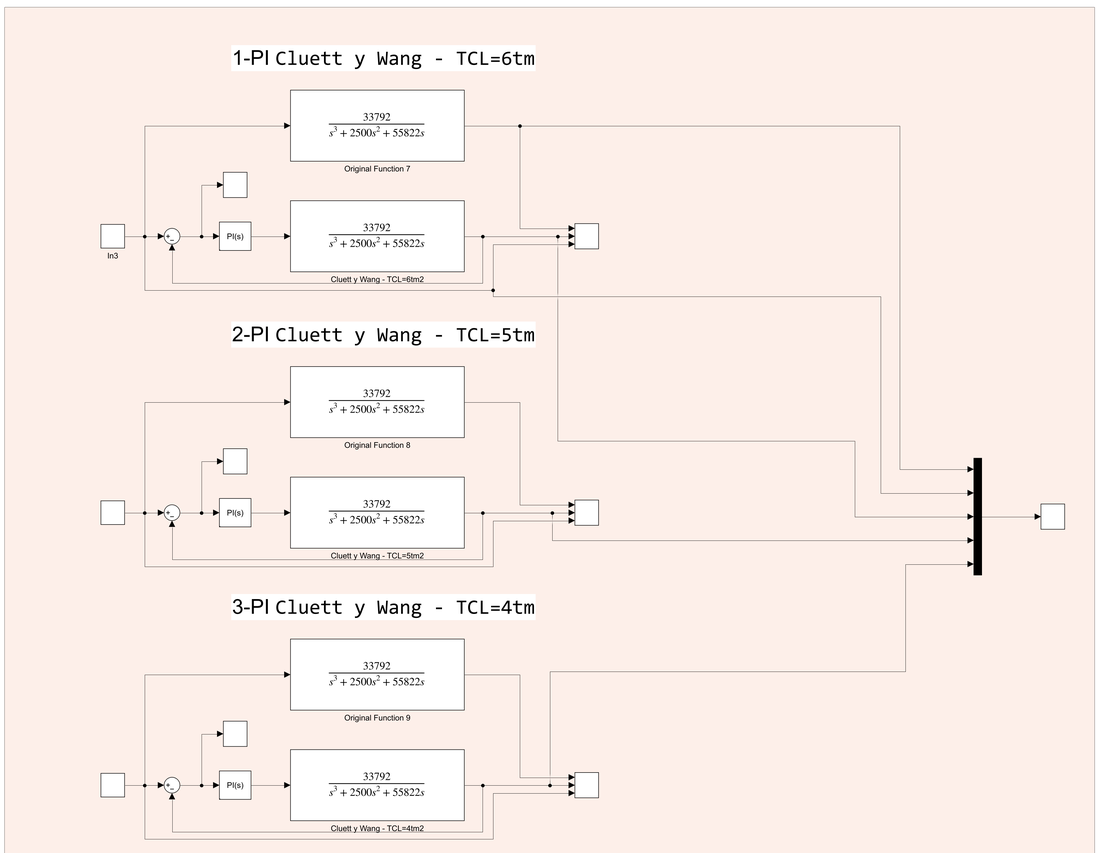
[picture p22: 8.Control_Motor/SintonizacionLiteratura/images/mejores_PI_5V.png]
3 mejores PI, 5 V
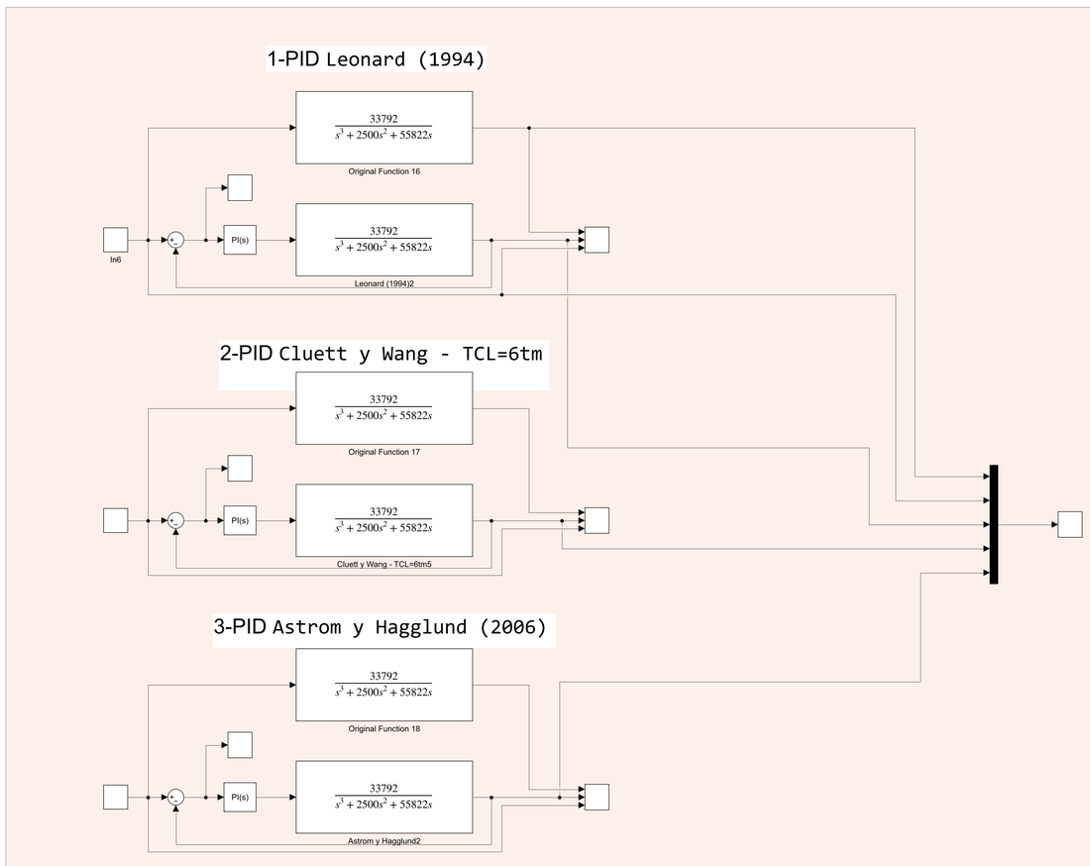
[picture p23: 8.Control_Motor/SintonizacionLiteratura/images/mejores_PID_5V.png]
3 mejores PID, 5 V
| **5 V** |  |  |

</div>

> **Ojo con el modelo:** los tres PID (Leonard, Cluett y Wang y Åström y Hägglund) están cargados con sus ganancias solo en el grupo de **1 V**. En los grupos de 2.5 V y 5 V los bloques de la columna *3 Best PID* quedaron como controladores de tipo **PI** con las ganancias de Cluett y Wang (se ve en la etiqueta `PI(s)` de los bloques), copiados de la columna de PI.

---

## 4. Resultados

Los tres PID se llevaron a la comparación final con los otros métodos (`ComparacionMetodos.slx`, referencia de 10 saltos acumulados). Valores del Excel [`Analisis5Metodos.xlsx`](../Analisis5Metodos.xlsx) (saltos 2 a 10):

<div align="center">

| Regla | Sobrepico | Ts observado |
|---|:-:|:-:|
| Leonard (1994) | ≈ 12.1 % | 1.7 – 2.8 s |
| Cluett y Wang ($T_{CL}=6\tau_m$) | ≈ 18.7 % | 2.2 – 2.8 s |
| Åström y Hägglund (2006) | ≈ 19.1 % | 1.4 – 1.7 s |

</div>

<p align="center">
  Comparación de los métodos en el salto de 20 grados
</p>

**Lectura:**

- Las tres reglas llevan el motor a la referencia en **1.4 – 2.8 s**, pero con **sobrepico alto**: entre 12 y 19 %.
- **Leonard (1994)** es la de menor sobrepico, aunque supera el 10 % que anuncia el libro. Es esperable que haya diferencia: la cifra del libro es para el modelo IPD ideal y aquí el modelo reemplaza dos polos de la planta por un retardo.
- **Åström y Hägglund (2006)** es la más rápida (Ts ≈ 1.5 s) y la de mayor sobrepico.
- **Cluett y Wang** es la más suave de las tres en esfuerzo de control (menor $K_p$ y $K_d$), pero tiene un sobrepico casi igual al de Åström y Hägglund y el Ts mayor del grupo.
- Frente a los otros dos métodos de la carpeta (asignación de polos y relé), estas reglas **quedan por detrás en sobrepico**; ver la [comparación general](../README.md).

Los tres PI de Cluett y Wang están en el modelo para probarse con 1, 2.5 y 5 de escalón, pero sus resultados no se tabularon en el Excel de comparación.

---

## 5. Observaciones

- **Las reglas son para un modelo aproximado.** El IPD reemplaza dos polos de la planta por un retardo; por eso el sobrepico real puede ser mayor que el que anuncia el libro.
- **Linealidad.** Los tres $K_m$ difieren menos de 1 % (0.6075, 0.6111 y 0.6130), de modo que el modelo IPD es válido en el rango de 1 a 5 V ensayado.
- **Bloque IPD de los modelos.** En `ControladoresLibro.slx` el bloque IPD de los tres ensayos usa $0.6075/s$ con retardo de 0.0464 s; las ganancias de los controladores se calcularon con el $K_m$ promedio (0.610).

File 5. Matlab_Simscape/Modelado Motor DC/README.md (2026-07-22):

# Modelado de un Motor DC en Simscape

Este documento explica el modelado de un **motor DC de excitación independiente constante**, tanto su deducción matemática (función de transferencia) como su implementación y verificación en **Simscape** (Matlab/Simulink).

El objetivo es obtener, por dos caminos independientes, la relación entre el voltaje de armadura aplicado $V(s)$ y las variables de interés del motor (corriente, torque, velocidad angular y posición angular), y comprobar que ambos caminos coinciden:

1. **Camino analítico:** deducción de las funciones de transferencia a mano, a partir de las ecuaciones eléctricas y mecánicas del motor.
2. **Camino en Simscape:** construcción del circuito físico del motor con bloques de Simscape y extracción de las funciones de transferencia con el **Model Linearizer**.

---

## 0. Modelo físico del motor DC

<p align="center">
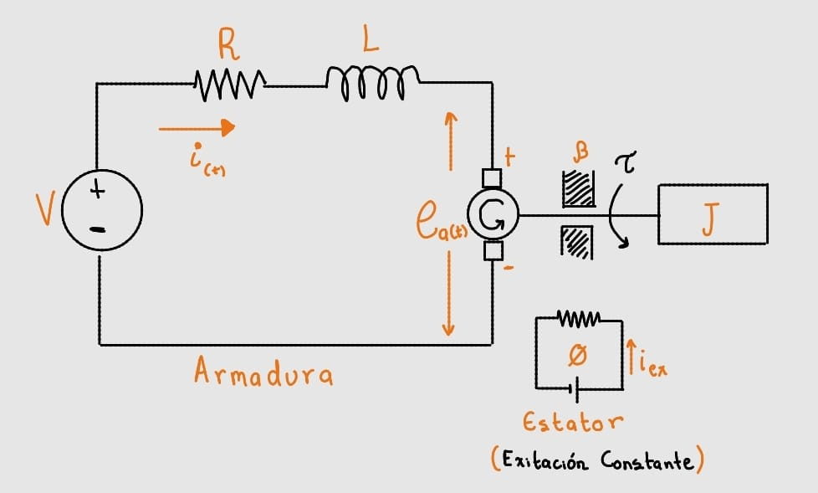
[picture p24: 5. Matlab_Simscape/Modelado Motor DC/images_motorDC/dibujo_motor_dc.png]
Diagrama físico del motor DC de armadura
  
</p>

El motor se modela de forma **simplificada, con flujo $\phi$ constante** en el estator (excitación constante). Por esta razón el estator no se modela como un circuito independiente: su efecto queda representado en dos constantes del motor, $K_a$ y $K_m$.

- **Circuito de armadura:** fuente de voltaje $V$, resistencia $R$, inductancia $L$ y corriente de armadura $i(t)$.
- **Fuerza contraelectromotriz:** $e_a(t)$, inducida en la armadura por el giro del motor.
- **Parte mecánica:** el motor entrega un torque $\tau$ a una inercia $J$, con un coeficiente de fricción viscosa $\beta$ que se opone al giro.

---

## 1. Modelo matemático (función de transferencia)

### 1.1 Constantes del motor

**$K_a$** — relación entre el voltaje inducido en la armadura y la velocidad angular del eje del motor:

$$e_a(t) = K_a \cdot \omega(t)$$

Aplicando la transformada de Laplace:

**(1)**

$$E_a(s) = K_a\, W(s)$$

**$K_m$** — relación entre el torque mecánico generado y la corriente que circula por la armadura:

$$\tau = K_m\, i(t)$$

Aplicando la transformada de Laplace:

**(2)**

$$I(s) = \frac{T(s)}{K_m}$$

### 1.2 Análisis de malla eléctrica y de inercia mecánica

**Malla eléctrica** (ley de voltajes de Kirchhoff en el circuito de armadura):

$$V(t) = R\,i(t) + L\,\frac{di}{dt} + e_a(t)$$

Aplicando la transformada de Laplace y despejando:

**(3)**

$$L\,s\,I(s) = V(s) - R\,I(s) - E_a(s)$$

**Inercia mecánica** (segunda ley de Newton para rotación, con fricción viscosa $\beta$):

$$J\ddot\theta = \tau - \beta\dot\theta$$

Aplicando la transformada de Laplace:

$$J s\, W(s) = T(s) - \beta\, W(s)$$

Despejando $W(s)$:

**(4)**

$$W(s) = \frac{T(s)}{Js+\beta}$$

### 1.3 Despeje de ecuaciones

Sustituyendo (1) y (2) en (3):

**(5)**

$$(Ls+R)\left(\frac{T(s)}{K_m}\right) + K_a\, W(s) = V(s)$$

Sustituyendo (4) en (5):

$$\left(\frac{Ls+R}{K_m}+\frac{K_a}{Js+\beta}\right)T(s) = V(s)$$

$$\left(\frac{(Ls+R)(Js+\beta)+K_m K_a}{K_m(Js+\beta)}\right)T(s) = V(s)$$

### 1.4 Funciones de transferencia resultantes

De la ecuación anterior se extraen las cuatro funciones de transferencia del sistema, todas con el mismo denominador característico:

$$
\frac{T(s)}{V(s)} = \frac{K_m(Js+\beta)}{JLs^2+(L\beta+RJ)s+R\beta+K_mK_a} \qquad \text{(Torque / Voltaje)}
$$

$$
\frac{W(s)}{V(s)} = \frac{K_m}{JLs^2+(L\beta+RJ)s+R\beta+K_mK_a} \qquad \text{(Velocidad angular / Voltaje)}
$$

$$
\frac{\theta(s)}{V(s)} = \frac{K_m}{s\big(JLs^2+(L\beta+RJ)s+R\beta+K_mK_a\big)} \qquad \text{(Posición angular / Voltaje)}
$$

$$
\frac{I(s)}{V(s)} = \frac{Js+\beta}{JLs^2+(L\beta+RJ)s+R\beta+K_mK_a} \qquad \text{(Corriente / Voltaje)}
$$

### 1.5 Valores numéricos usados

<div align="center">

| Parámetro | Valor |
|---|---|
| $R$ | $10\ \Omega$ |
| $L$ | $40\ \text{mH} = 0.04\ \text{H}$ |
| $J$ | $0.9\ \text{Kg·m}^2$ |
| $\beta$ | $0.3\ \text{Nms/rad}$ |
| $K_m$ | $0.1\ \text{V·s/rad}$ |
| $K_a$ | $0.1\ \text{V·s/rad}$ |

</div>

Sustituyendo estos valores (y normalizando dividiendo entre $JL=0.036$), las funciones de transferencia quedan:

$$
\boxed{\dfrac{T(s)}{V(s)} = \dfrac{2.5\,s+0.833}{s^2+250.35\,s+83.61}}
\qquad
\boxed{\dfrac{W(s)}{V(s)} = \dfrac{2.777}{s^2+250.35\,s+83.61}}
$$

$$
\boxed{\dfrac{\theta(s)}{V(s)} = \dfrac{2.777}{s^3+250.35\,s^2+83.61\,s}}
\qquad
\boxed{\dfrac{I(s)}{V(s)} = \dfrac{25\,s+8.33}{s^2+250.35\,s+83.61}}
$$

Estas cuatro funciones de transferencia son el resultado analítico que se va a **contrastar** con lo que arroje Simscape en la sección siguiente.

---

## 2. Modelo en Simscape

<p align="center">
  Modelo del motor DC construido en Simscape
</p>

El circuito físico del motor se construyó directamente con bloques de Simscape, replicando el diagrama de la sección 0:

- **Fuente de voltaje controlada** (`V`), alimentada por un escalón (`Step`), que representa $V(t)$.
- **Resistencia** (`R`) e **inductancia** (`L`) en serie, representando el circuito de armadura.
- **Sensor de corriente** (`A`), que mide $i(t)$.
- **Rotational Electromechanical Converter**, el bloque que traduce el dominio eléctrico al dominio mecánico rotacional (equivale físicamente al motor: aquí se aplican $K_m$ y $K_a$).
- **`Jm`** (Ideal Torque Sensor + inercia): representa la inercia $J$ del sistema mecánico.
- **`Dm`** (amortiguador rotacional ideal): representa la fricción viscosa $\beta$.
- **Ideal Rotational Motion Sensor**: mide torque, velocidad angular y posición angular en el eje.
- Bloque de referencia mecánica (`f(x)=0`) y tierra eléctrica, necesarios para cerrar los dominios físicos de Simscape.
- Cuatro salidas conectadas a osciloscopios: `tao` (torque), `omega` (velocidad angular), `thetha` (posición angular) e `I` (corriente).

### 2.1 Bloques principales utilizados

<p align="center">
  Bloques de Simscape utilizados en el modelo
</p>

<div align="center">

| Bloque | Función en el modelo |
|---|---|
| Controlled Voltage | Fuente de voltaje de armadura $V(t)$ |
| R1 | Resistencia de armadura $R$ |
| L1 | Inductancia de armadura $L$ |
| Current Sensor | Mide la corriente de armadura $i(t)$ |
| Rotational Electromechanical Converter | Convierte el dominio eléctrico al dominio mecánico rotacional (relaciona $K_m$, $K_a$) |
| Ideal Rotational Motion Sensor | Mide velocidad angular ($\omega$) y posición angular ($\theta$) del eje |
| Ideal Torque Sensor | Mide el torque $\tau$ transmitido en el eje |
| Jm1 | Inercia rotacional $J$ |
| Dm1 | Amortiguador rotacional (fricción viscosa) $\beta$ |

</div>

---

## 3. Extracción de las funciones de transferencia con el Model Linearizer

Con el modelo ya armado y parametrizado con los valores de la sección 1.5, se usa la herramienta **Model Linearizer** de Matlab para linealizar el sistema y obtener sus funciones de transferencia de forma automática.

### 3.1 Configurar entradas y salidas de análisis

<p align="center">
  Configuración de puntos de análisis lineal
</p>

Sobre cada señal del modelo se hace clic derecho → **Linear Analysis Points**, y se define:

- La señal de voltaje `V` como **Input Perturbation** (entrada del sistema a linealizar).
- Las señales `tao`, `omega`, `thetha` e `I` como **Output Measurement** (salidas a medir).

Esto le indica a Matlab exactamente qué relación entrada-salida se quiere linealizar (equivalente a definir $V(s)$ como entrada y $T(s)$, $W(s)$, $\theta(s)$, $I(s)$ como salidas, tal como en la sección 1).

### 3.2 Abrir el Model Linearizer

<p align="center">
  Apertura del Model Linearizer desde la pestaña Apps
</p>

Desde la pestaña **APPS** de Simulink se abre la app **Model Linearizer**.

### 3.3 Ejecutar la linealización (Step)

<p align="center">
  Ejecución de la linealización con Step en el Model Linearizer
</p>

Dentro del Model Linearizer, se presiona el botón **Step**. Esto linealiza el modelo alrededor del punto de operación (condición inicial) y:

- Genera automáticamente las gráficas de respuesta al escalón para cada salida configurada.
- Crea la variable `linsys1` en el **Linear Analysis Workspace**, un modelo en espacio de estados de **1 entrada, 4 salidas y 3 estados** — coincide exactamente con el orden del sistema obtenido a mano (denominador de segundo grado para $T,W,I$ y de tercer grado para $\theta$, es decir, 3 estados en total).

### 3.4 Ver el resultado como función de transferencia

<p align="center">
  Detalle del resultado de linealización mostrado como función de transferencia
</p>

Haciendo doble clic sobre `linsys1` y seleccionando **Display linearization result as: Transfer Function**, Matlab muestra las cuatro funciones de transferencia obtenidas por linealización numérica del modelo físico.

---

## 4. Verificación de consistencia

Comparando el resultado del Model Linearizer con las funciones de transferencia obtenidas a mano en la sección 1.4, se observa que **coinciden los mismos coeficientes**:

<div align="center">

| Salida | Función de transferencia (Simscape) | Coincide con |
|---|---|---|
| $I(s)/V(s)$ | $\dfrac{25s+8.333}{s^2+250.3s+83.61}$ | Corriente / Voltaje (sección 1.4) |
| $W(s)/V(s)$ | $\dfrac{2.778}{s^2+250.3s+83.61}$ | Velocidad angular / Voltaje |
| $\theta(s)/V(s)$ | $\dfrac{2.778}{s^3+250.3s^2+83.61s}$ | Posición angular / Voltaje |
| $T(s)/V(s)$ | $\dfrac{2.5s+0.833}{s^2+250.3s+83.61}$ | Torque / Voltaje |

</div>

El hecho de que el modelo físico armado bloque a bloque en Simscape y el modelo matemático deducido analíticamente arrojen **las mismas funciones de transferencia** confirma que:

1. Las ecuaciones eléctricas y mecánicas se plantearon correctamente.
2. Los bloques de Simscape (y sus parámetros $R$, $L$, $J$, $\beta$, $K_m$, $K_a$) representan fielmente al motor DC modelado.
3. El sistema queda listo para diseñar y probar controladores sobre estas funciones de transferencia en las siguientes etapas del proyecto.

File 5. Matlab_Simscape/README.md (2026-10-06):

# 5. Matlab_Simscape

Esta carpeta contiene el modelado y la simulación dinámica del robot SCARA en **Matlab/Simulink**, usando **Simscape Multibody** a partir del ensamble 3D desarrollado previamente en SolidWorks. El objetivo es trasladar la geometría, las masas, las inercias y las restricciones cinemáticas del CAD hacia un entorno de simulación multicuerpo, para validar allí tanto la **cinemática directa** como la **cinemática inversa** calculadas analíticamente en las carpetas [`3.Cinematica_Directa`](../3.Cinematica_Directa) y [`4.Cinematica_Inversa`](../4.Cinematica_Inversa).

## Contenido de la carpeta

| Elemento | Descripción |
| --- | --- |
| `EnsamblajeFinal.xml` | Archivo de descripción multicuerpo exportado desde SolidWorks mediante Simscape Multibody Link. |
| `Parte1_Predeterminado_sldprt.STEP`, `Parte2_Predeterminado_sldprt.STEP`, `Parte3_Predeterminado_sldprt.STEP` | Geometría (mallas STEP) de cada eslabón, exportada junto con el XML para la representación 3D dentro de Simscape. |
| `SLXCinematicaDirecta.slx` | Modelo de Simulink que aplica una trayectoria articular deseada (θ1, θ2, d3) y anima el robot: cinemática directa. |
| `SLXCinematicaInversa.slx` | Modelo de Simulink que, a partir de un punto inicial y un punto final en coordenadas cartesianas, calcula las variables articulares necesarias (desacoplamiento geométrico) y anima el robot: cinemática inversa. |
| `ENSAMBLE.png`, `ESLABON1.png`, `ESLABON2.png`, `PRISMATICA.png` | Imágenes de cada eslabón/subsistema, usadas para personalizar visualmente los bloques del modelo en Simulink. |

> 📌 Los archivos `.STEP` y el `.xml` son generados automáticamente por el complemento **Simscape Multibody Link** de SolidWorks; no deben editarse manualmente, ya que cualquier cambio en el CAD requiere volver a exportarlos.

## 1. Requisitos previos

Antes de exportar o simular es necesario tener instalados y habilitados los siguientes complementos:

**En Matlab:** el paquete **Simscape Multibody** debe estar instalado desde el *Add-On Explorer*. Este paquete permite modelar y simular sistemas mecánicos multicuerpo en 3D (robots, suspensiones, tren de aterrizaje, etc.), formulando y resolviendo automáticamente las ecuaciones de movimiento del sistema completo, e incluye la posibilidad de importar ensambles CAD completos (masas, inercias, juntas, restricciones y geometría 3D).

<p align="center">
  
</p>

**En SolidWorks:** en el menú **Complementos**, deben activarse **Simscape Multibody Link** (el enlace que permite exportar el ensamble hacia Matlab) y, opcionalmente, **SW2URDF** si más adelante se va a trabajar la carpeta `7. URDF`.

<p align="center">
  
</p>

## 2. Exportación del ensamble desde SolidWorks

Con el CAD completo del robot ya armado —y simplificado en la mayor medida posible para aligerar la simulación (eliminando chaflanes, agujeros de tornillería, redondeos menores, etc.)— se exporta el ensamble hacia Simscape Multibody desde:

`Herramientas > Simscape Multibody Link > Export > Simscape Multibody...`

<p align="center">
  
</p>

Este proceso genera automáticamente:
- Un archivo **`.xml`** con la descripción del árbol de cuerpos, juntas, sistemas de coordenadas y propiedades de masa/inercia de cada pieza.
- Un archivo **`.STEP`** por cada pieza del ensamble, usado para la representación gráfica 3D dentro de Simulink.

## 3. Importación en Matlab

Ya en Matlab, el archivo `.xml` se importa con la función `smimport`, indicando el nombre del archivo exportado:

```matlab
smimport("EnsamblajeFinal.xml")
```

<p align="center">
  
</p>

Al ejecutar `smimport`, Matlab genera automáticamente un modelo `.slx` con todos los cuerpos (bloques `Solid`), las juntas (`Revolute`, `Prismatic`) y las transformaciones necesarias para reconstruir la cinemática del ensamble tal como estaba definida en SolidWorks.

## 4. Estructura general del modelo generado

Al finalizar la importación, el modelo `.slx` queda con la disposición general que se muestra a continuación: el bloque **World** como referencia inercial, un bloque **Transform** de posicionamiento inicial, y la cadena cinemática del robot compuesta por los cuerpos rígidos (`Parte1_1_RIGID`, `Parte2_1_RIGID`, `Parte3_1_RIGID`, `CremalleraDesde0_1_RIGID`) enlazados mediante las juntas `Revolute`, `Revolute1` y `Prismatic`, que corresponden a las dos articulaciones rotacionales y a la articulación prismática del SCARA.

<p align="center">
  
</p>

### Interior de los subsistemas `RIGID`

Cada bloque `_RIGID` es en realidad un subsistema que encapsula el sólido (`Solid`, con su geometría y propiedades de masa/inercia importadas del CAD), un `ReferenceFrame` y un par de bloques `Transform`, encargados de ubicar correctamente los puertos de entrada (`F`) y salida (`F1`) de la junta respecto al marco de referencia de la pieza.

<p align="center">
  
</p>

## 5. Instrumentación del modelo: sensores y entradas de movimiento

Con la cadena cinemática ya armada, se agregan las entradas de movimiento (`Motion Input`) en cada una de las juntas —las dos revolutas y la prismática— para poder excitarlas con las señales articulares (θ1, θ2, d3) provenientes de la cinemática directa o inversa. De forma paralela, se añaden **sensores de transformación** (`Transform Sensor`) en cada eslabón y en el efector final, para poder medir y graficar la posición/orientación real del robot durante la simulación.

<p align="center">
  
</p>

### Organización de las transformadas internas

Como mejora, dentro de cada subsistema `RIGID` las transformadas se reorganizan **en serie** (por ejemplo, una traslación en X seguida de una traslación en Z), en lugar de dejarlas como una única transformada compuesta. Esto facilita revisar y depurar visualmente cada desplazamiento geométrico de la pieza respecto a su marco de referencia.

<p align="center">
  
</p>

## 6. Organización final del modelo

En la versión final del modelo se mejora la presentación general: se asignan **imágenes representativas** a cada eslabón y a la articulación prismática (base, `LINK 1`, `LINK 2` y `RACK`), de modo que el diagrama de bloques se identifica visualmente con la pieza real del robot. Además, las entradas articulares ya no se generan manualmente, sino mediante un bloque **Matlab Function**, con dos variantes:

- Una función **`DesiredTrajectory`** para la **cinemática directa**, que interpola linealmente θ1, θ2 y d3 entre una posición inicial y una posición final dadas directamente como ángulos/desplazamiento articular.
- Una función **`DesiredTrajectory`** (con soporte de cinemática inversa) que recibe un punto cartesiano inicial y uno final del efector, calcula las variables articulares correspondientes mediante desacoplamiento geométrico, y luego interpola entre ellas.

<p align="center">
  
</p>

## 7. Resultado: animación y verificación

Finalmente, al correr la simulación desde el **Mechanics Explorer** de Simscape, se observa la animación 3D completa del robot ensamblado (base, `LINK 1`, `LINK 2` y `RACK`), confirmando que el efector alcanza correctamente la posición final deseada, tanto para la trayectoria definida por cinemática directa como para la calculada por cinemática inversa.

<p align="center">
  
</p>

## 8. Código: cinemática directa (`SLXCinematicaDirecta.slx`)

La función `DesiredTrajectory` genera una trayectoria articular interpolada linealmente en el tiempo, entre una posición inicial (home) y una posición final expresada directamente en variables articulares (θ1, θ2, Pz):

```matlab
function [theta1, theta2, Pz] = DesiredTrajectory(t)
    t_max = 5;

    theta10 = 0.0;
    theta20 = 0.0;
    Pz0     = 0.0;

    theta11 = theta10 + deg2rad(40);
    theta21 = theta20 + deg2rad(57);
    Pz1     = Pz0 + (3.5)/100;

    theta1 = theta10 + (theta11 - theta10) * (t / t_max);
    theta2 = theta20 + (theta21 - theta20) * (t / t_max);
    Pz     = Pz0    + (Pz1    - Pz0)    * (t / t_max);
end
```

- `t_max` define la duración total del movimiento (5 s).
- Se parte de una posición articular de referencia (`theta10`, `theta20`, `Pz0` = 0) hasta llegar a `theta11 = 40°`, `theta21 = 57°` y un desplazamiento prismático `Pz1 = 3.5 cm`.
- La interpolación es lineal respecto al tiempo normalizado `t / t_max`, entregando en cada instante los valores de θ1, θ2 y Pz que alimentan directamente las juntas `Revolute`, `Revolute1` y `Prismatic` del modelo.

## 9. Código: cinemática inversa (`SLXCinematicaInversa.slx`)

A diferencia del caso anterior, aquí la trayectoria se define en el **espacio cartesiano** (posición del efector Px, Py, Pz), y la función interna `calcIK` resuelve las variables articulares mediante **desacoplamiento geométrico** (ley de cosenos para θ1 y θ2, y despeje directo para d3), consistente con el desarrollo analítico de la carpeta [`4.Cinematica_Inversa`](../4.Cinematica_Inversa):

```matlab
function [theta1, theta2, d3] = DesiredTrajectory(t)
    %% Parámetros del robot (en cm)
    l1 = 15.554;
    l2 = 16.190;
    h1 = 12.57;
    h2 = 0.87;
    h3 = 0.41;
    h4 = 5.40;
    r1 = 1.054;
    t_max = 5;

    %% Punto inicio (posicion home)
    Px0 = 32.798;  Py0 = 0.0001;  Pz0 = 8.45;

    %% Punto destino
    Px1 = 10.9960; Py1 = 26.0672;  Pz1 = 4.95;

    %% Cinematica inversa punto inicio
    [th1_0, th2_0, d3_0] = calcIK(Px0, Py0, Pz0, l1, l2, h1, h2, h3, h4, r1);

    %% Cinematica inversa punto destino
    [th1_1, th2_1, d3_1] = calcIK(Px1, Py1, Pz1, l1, l2, h1, h2, h3, h4, r1);

    %% Interpolar en angulos (igual que la cinematica directa)
    s      = max(0, min(1, t / t_max));
    theta1 = th1_0 + (th1_1 - th1_0) * s;
    theta2 = th2_0 + (th2_1 - th2_0) * s;
    d3     = d3_0  + (d3_1  - d3_0)  * s;
end

%% -------------------------------------------------------
function [theta1, theta2, d3] = calcIK(Pxd, Py, Pz, l1, l2, h1, h2, h3, h4, r1)
    Px = Pxd - r1;
    b  = sqrt(Px^2 + Py^2);

    cos_t2 = (b^2 - l1^2 - l2^2) / (2*l1*l2);
    cos_t2 = max(-1, min(1, cos_t2));
    sen_t2 = sqrt(1 - cos_t2^2);
    theta2 = atan2(sen_t2, cos_t2);

    alpha  = atan2(Py, Px);
    phi    = atan2(l2*sen_t2, l1 + l2*cos_t2);
    theta1 = alpha - phi;

    d3 = (h1 + h2 + h3 - h4 - Pz) / 100;
end
```

**Notas sobre los parámetros:**
- `l1`, `l2`: longitudes de los eslabones 1 y 2 (cm).
- `h1`, `h2`, `h3`, `h4`: alturas geométricas del robot usadas para relacionar la coordenada `Pz` del efector con el desplazamiento `d3` de la articulación prismática.
- `r1`: excentricidad/offset en X entre el eje de la base y el primer eslabón, que se resta a `Px` antes de resolver el triángulo formado por `l1` y `l2`.
- `calcIK` aplica **ley de cosenos** para obtener `θ2` a partir de la distancia `b` al punto objetivo, y luego obtiene `θ1` como la diferencia entre el ángulo del vector al efector (`alpha`) y el ángulo interno del triángulo (`phi`).
- El `s = max(0, min(1, t/t_max))` satura la interpolación para evitar extrapolar fuera del intervalo `[0, t_max]`.

## 10. Comparación cuantitativa: analítico vs Simscape

Para cerrar el ciclo se compararon los resultados de las carpetas [`3.Cinematica_Directa`](../3.Cinematica_Directa) y [`4.Cinematica_Inversa`](../4.Cinematica_Inversa) con lo que entrega Simscape. Se simularon los dos modelos (5 s) y se tomó la **posición del efector** del bloque `Transform Sensor8` (la misma señal que muestran los `Display` del modelo, pasada de m a cm). Los valores analíticos son los de la matriz $T_4^0$ y los de las ecuaciones de la inversa, con las dimensiones de la sección 9.

### 10.1 Cinemática directa (`SLXCinematicaDirecta.slx`)

Entrada: $\theta_1=40^\circ$, $\theta_2=57^\circ$, $d_3=3.5$ cm.

<div align="center">

| Posición del efector [cm] | $p_x$ | $p_y$ | $p_z$ |
|---|:-:|:-:|:-:|
| Analítico ($T_4^0$) | 10.9960 | 26.0672 | 4.9500 |
| Simscape | 11.0105 | 26.0640 | 4.9514 |
| Error | 0.0145 | −0.0033 | 0.0014 |

</div>

Norma del error: **0.0149 cm** (0.15 mm). En la posición inicial (todas las articulaciones en 0) Simscape da $(32.7978,\ -0.0015,\ 8.4500)$ contra el $(32.7980,\ 0,\ 8.4500)$ analítico.

### 10.2 Cinemática inversa (`SLXCinematicaInversa.slx`)

Puntos del modelo: inicio $(32.798,\ 0.0001,\ 8.45)$ y destino $(10.9960,\ 26.0672,\ 4.95)$ cm.

<div align="center">

| | $\theta_1$ | $\theta_2$ | $d_3$ [cm] |
|---|:-:|:-:|:-:|
| Inversa analítica, inicio | 0.0002° | 0.0000° | 0.0000 |
| Inversa analítica, destino | 39.9998° | 57.0003° | 3.5000 |
| Simscape, final ($t=5$ s) | 39.9838° | 56.9775° | 3.4986 |

</div>

El destino de la inversa es, a propósito, **el mismo punto de la cinemática directa** ($40^\circ,\ 57^\circ,\ 3.5$ cm): al evaluar la directa con los ángulos de la inversa se recupera $(10.9960,\ 26.0672,\ 4.9500)$, y los dos modelos de Simscape terminan en la misma pose.

<div align="center">

| Posición del efector [cm] | $p_x$ | $p_y$ | $p_z$ | $\lVert e\rVert$ |
|---|:-:|:-:|:-:|:-:|
| Objetivo, final | 10.9960 | 26.0672 | 4.9500 | |
| Simscape, final | 11.0105 | 26.0639 | 4.9514 | 0.0149 |
| Simscape, $t=2.5$ s | 26.3904 | 17.4529 | 6.6989 | |
| Directa con las articulaciones interpoladas en $t=2.5$ s | 26.3978 | 17.4454 | 6.7000 | 0.0106 |

</div>

La interpolación del modelo es **lineal en las articulaciones**, no en el espacio cartesiano; por eso el punto intermedio se compara contra la cinemática directa de los ángulos interpolados, y no contra el punto medio de la recta entre los dos puntos.

### 10.3 Conclusión

- El error máximo del efector es de **0.015 cm (0.15 mm)**, cerca del 0.05 % de la longitud total $l_1+l_2$: la cinemática analítica y el modelo multicuerpo importado del CAD **coinciden**.
- Al final de los 5 s las articulaciones de Simscape quedan unas centésimas por debajo de la consigna (0.016° en $\theta_1$, 0.023° en $\theta_2$, 0.0014 cm en $d_3$), lo que equivale a un retraso de apenas ≈ 2 ms respecto a la rampa. Es el orden de magnitud del filtrado de entrada de los conversores Simulink-PS, y no una diferencia del modelo geométrico.

## Estado de esta sección

- [x] Instalación y verificación de requisitos (Simscape Multibody en Matlab / Simscape Multibody Link en SolidWorks)
- [x] Exportación del ensamble desde SolidWorks
- [x] Importación del modelo multicuerpo en Matlab (`smimport`)
- [x] Construcción y organización del modelo en Simulink (RIGID, transformadas, sensores, motion inputs)
- [x] Simulación de cinemática directa (`SLXCinematicaDirecta.slx`)
- [x] Simulación de cinemática inversa (`SLXCinematicaInversa.slx`)
- [x] Comparación cuantitativa entre resultados analíticos (carpetas 3 y 4) y resultados de Simscape

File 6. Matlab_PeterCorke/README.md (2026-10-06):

# Cinemática Inversa del SCARA con Peter Corke (Robotics Toolbox)

Esta carpeta lleva la **cinemática inversa** del robot SCARA (ya deducida a mano en [`4.Cinematica_Inversa`](../4.Cinematica_Inversa/README.md)) a MATLAB usando el **Robotics Toolbox de Peter Corke (RTB 10.4)**. El flujo es:

1. Se calcula $\theta_1$, $\theta_2$ y $d_3$ con las fórmulas analíticas (geometría + ley de cosenos).
2. Se construye el robot en el toolbox con la **tabla DH** de la [cinemática directa](../3.Cinematica_Directa/README.md) (`Link` + `SerialLink`).
3. Se **verifica** con `fkine`: al meter los ángulos calculados, el toolbox debe devolver exactamente el punto del que se partió. Si coincide, el ciclo directa ⇄ inversa queda cerrado y el modelo DH es correcto.
4. Se dibuja el robot (`plot`) y se puede mover con sliders (`teach`).

> El toolbox **no resuelve** la inversa por ti en este caso: la resolvemos analíticamente y el toolbox sirve para **comprobarla y visualizarla**.

---

## 0. Contenido de la carpeta

<div align="center">

| Archivo | Qué hace |
|---|---|
| `Inv_PetCor_Proy_BASETRASL.m` | Modelo de **3 `Link`** (θ₁, θ₂, d₃). La fila 1 de la tabla DH (traslación $r_1$ en $x$ y $h_1$ en $z$) se absorbe en `Robot.base`. Punto de prueba **B**. |
| `Inv_PetCor_Proy_BASEREVOL.m` | Modelo de **4 `Link`**: la fila 1 de la tabla DH se deja como un joint revoluto **bloqueado** (`qlim = [0 0]`). Punto de prueba **A**. |
| `images/` | Capturas del robot en el toolbox y la figura de la geometría de la inversa usadas en este documento. |

</div>

Los dos scripts dan **el mismo robot y el mismo resultado**; solo cambia cómo se representa la primera fila de la tabla DH (sección 3).

### Cómo ejecutarlo

1. Tener instalado el Robotics Toolbox de Peter Corke (carpeta `rvctools`) y activarlo **una vez por sesión** de MATLAB:

   ```matlab
   run('ruta/a/rvctools/startup_rvc.m')
   ```

2. Abrir el script (`BASETRASL` o `BASEREVOL`), editar el punto objetivo (`Pxd`, `Py`, `Pz`) y presionar **Run**.
3. En la consola salen $\theta_2$, $\theta_1$ (en grados) y $d_3$ (en cm); se abre la figura del robot, la ventana `teach` con sliders y se imprime la matriz `fkine`.

> Todas las longitudes están en **centímetros**; los ángulos se calculan en radianes y se imprimen en grados.

---

## 1. Parámetros del robot

<div align="center">

| Símbolo | Variable en MATLAB | Valor | Significado |
|---|---|---|---|
| $l_1$ | `l1` | 15.554 cm | Eslabón 1 (hombro → codo) |
| $l_2$ | `l2` | 16.190 cm | Eslabón 2 (codo → muñeca) |
| $h_1$ | `h1` | 12.57 cm | Altura de la base a $\lbrace 1\rbrace$ |
| $h_2$ | `h2` | 0.87 cm | Altura entre $\lbrace 1\rbrace$ y $\lbrace 2\rbrace$ |
| $h_3$ | `h3` | 0.41 cm | Altura entre $\lbrace 2\rbrace$ y $\lbrace 3\rbrace$ |
| $h_4$ | `h4` | 5.40 cm | Parte fija de la altura de la prismática |
| $r_1$ | `r1` | 1.054 cm | Offset en $x$ entre la base y el eje de $\theta_1$ |

</div>

Variables articulares: $q=[\theta_1,\ \theta_2,\ d_3]$.

---

## 2. Del modelo DH al toolbox

La tabla DH del robot (sección 2.2 de la [cinemática directa](../3.Cinematica_Directa/README.md)) es:

<div align="center">

| $i$ | $\theta_i$ | $d_i$ | $\alpha_i$ | $a_i$ |
|---|---|---|---|---|
| 1 | $0$ | $h_1$ | $0$ | $r_1$ |
| 2 | $\theta_1$ | $h_2$ | $0$ | $l_1$ |
| 3 | $\theta_2$ | $h_3$ | $\pi$ | $l_2$ |
| 4 | $0$ | $h_4+d_3$ | $0$ | $0$ |

</div>

En Peter Corke cada fila es un `Link`. La regla es: lo que es **constante** se pasa como parámetro, y lo que es **variable** lo pone `fkine/plot` a través de $q$.

<div align="center">

| Fila | Código | Qué pasa con la variable |
|---|---|---|
| 1 | `Link('revolute','d',h1,'alpha',0,'a',r1)` | $\theta$ fijo en 0 (no se mueve) |
| 2 | `Link('revolute','d',h2,'alpha',0,'a',l1)` | $\theta = q = \theta_1$ |
| 3 | `Link('revolute','d',h3,'alpha',-pi,'a',l2)` | $\theta = q = \theta_2$ |
| 4 | `Link('prismatic','theta',0,'alpha',0,'a',0,'offset',h4)` | $d = q + \text{offset} = d_3 + h_4$ |

</div>

Detalles importantes:

- **`'offset', h4` en la prismática:** en un `Link` prismático, `offset` se **suma a $d$**. Por eso el toolbox arma $d_4 = d_3 + h_4$, tal cual la tabla, y $d_3$ queda como la única variable.
- **`'alpha', -pi` en lugar de `pi`:** $\cos(\pm\pi)=-1$ y $\sin(\pm\pi)\approx 0$, así que la matriz resultante es la misma (la diferencia es del orden de $10^{-16}$). Es el giro de 180° sobre $x$ que invierte el eje $z$ en el eslabón 3 y es el que hace que $p_z$ **baje** cuando $d_3$ aumenta.
- **Límites:** `qlim = [0, 5.4]` limita la prismática a su carrera real, 0–5.4 cm (útil para `teach`, que no deja pasar el slider de ese rango). Es la misma carrera del URDF (`upper = 0.054` m).

---

## 3. Las dos formas de modelar la fila 1

La fila 1 de la tabla DH **no mueve nada**: solo traslada $r_1$ en $x$ y $h_1$ en $z$. Hay dos formas válidas de ponerla en el toolbox:

### 3.1 `BASETRASL` — se absorbe en `Robot.base` (3 joints)

```matlab
R(1) = Link('revolute',  'd', h2, 'alpha',  0,  'a', l1, 'offset', 0);   % θ1
R(2) = Link('revolute',  'd', h3, 'alpha', -pi, 'a', l2, 'offset', 0);   % θ2
R(3) = Link('prismatic', 'theta', 0, 'alpha', 0, 'a', 0, 'offset', h4);  % d3
Robot = SerialLink(R, 'name', 'SCARA');
Robot.base = transl(r1, 0, h1);   % = T_1^0
```

- `transl(r1,0,h1)` es exactamente la matriz $T_1^0$ de la cinemática directa.
- El vector de joints es el natural: `q = [θ1, θ2, d3]`.
- Es la opción más limpia: **3 GDL = 3 joints**.

### 3.2 `BASEREVOL` — joint bloqueado (4 joints)

```matlab
R(1) = Link('revolute','d',h1,'alpha',0,'a',r1,'offset',0);
R(1).qlim = [0, 0];                       % joint bloqueado
R(2) = Link('revolute',  'd', h2, 'alpha', 0,   'a', l1, 'offset', 0);
R(3) = Link('revolute',  'd', h3, 'alpha', -pi, 'a', l2, 'offset', 0);
R(4) = Link('prismatic', 'theta', 0, 'alpha', 0, 'a', 0, 'offset', h4);
```

- Respeta la tabla DH **fila por fila** (4 `Link`), útil para comparar contra la tabla.
- El primer joint es "de mentira": `qlim = [0 0]` y siempre se le pasa 0, por eso el vector de joints tiene **4 entradas**: `q = [0, θ1, θ2, d3]`.

> **Ojo con el orden:** en `BASEREVOL` hay un corrimiento. $\theta_1$ va en `q2`, $\theta_2$ en `q3` y $d_3$ en `q4` (el script lo deja comentado). Si se pasa `[θ1, θ2, d3]` a este modelo, el resultado es incorrecto.

<div align="center">

| | `BASETRASL` | `BASEREVOL` |
|---|---|---|
| Nº de `Link` | 3 | 4 |
| Fila 1 de la DH | `Robot.base = transl(r1,0,h1)` | `Link` bloqueado con `qlim=[0 0]` |
| Vector `q` | `[θ1, θ2, d3]` | `[0, θ1, θ2, d3]` |
| Resultado `fkine` | idéntico | idéntico |

</div>

---

## 4. Cinemática inversa paso a paso

La deducción completa (con todos los triángulos) está en la [carpeta 4](../4.Cinematica_Inversa/README.md). Aquí está el **procedimiento tal como se implementa en el código**, con un ejemplo numérico completo.

**Datos del ejemplo (punto B, `BASETRASL`):**

$$p_x = 14.6053,\quad p_y = 25.5112,\quad p_z = 8.450 \ \text{cm}$$

<p align="center">
  Vista superior de la geometría de la inversa para el punto B
</p>

> **Nombres en el código:** el script llama `Pxd` al $p_x$ deseado y `Px` al valor ya corregido por $r_1$ (lo que en la carpeta 4 se llama $\rho_x$). `Py` es $\rho_y=p_y$.

### Paso 1 — Descontar el offset de la base ($r_1$)

El eje de $\theta_1$ está desplazado $r_1$ en $x$ respecto al origen $\lbrace 0\rbrace$. Para trabajar desde el hombro se resta:

$$\rho_x = p_x - r_1 \qquad \rho_y = p_y$$

```matlab
Px = Pxd - r1;
```

$$\rho_x = 14.6053 - 1.054 = 13.5513 \qquad \rho_y = 25.5112$$

### Paso 2 — Distancia hombro → punto ($b$)

Pitágoras en el plano $xy$:

$$b = \sqrt{\rho_x^2+\rho_y^2}$$

```matlab
b = sqrt(Px^2 + Py^2);
```

$$b = \sqrt{13.5513^2 + 25.5112^2} = 28.8870 \text{ cm}$$

**Chequeo de alcance:** el punto solo es alcanzable si $|l_1-l_2| \le b \le l_1+l_2$, es decir $0.636 \le b \le 31.744$ cm. Aquí $28.887$ está dentro. ✅

### Paso 3 — $\cos\theta_2$ (ley de cosenos)

Con $\beta=180^\circ-\theta_2$ el triángulo $l_1,\ l_2,\ b$ da:

$$\cos\theta_2 = \frac{b^2 - l_1^2 - l_2^2}{2\,l_1 l_2}$$

```matlab
cos_theta2 = (b^2 - l1^2 - l2^2) / (2*l1*l2);
cos_theta2 = max(-1, min(1, cos_theta2));   % protección numérica
```

$$\cos\theta_2 = \frac{834.46 - 241.93 - 262.12}{2(15.554)(16.190)} = \frac{330.42}{503.64} = 0.65606$$

> **¿Para qué el `max/min`?** Por redondeo, en el borde del espacio de trabajo el coseno puede salir $1.0000000000001$. Sin esa línea, el siguiente paso calcularía la raíz de un negativo y daría un número **complejo**.

### Paso 4 — $\sin\theta_2$ y la configuración del brazo

De $\sin^2+\cos^2=1$:

$$\sin\theta_2 = \pm\sqrt{1-\cos^2\theta_2}$$

```matlab
sen_theta2 = sqrt(1 - cos_theta2^2);     % signo +
```

$$\sin\theta_2 = +\sqrt{1-0.65606^2} = 0.75471$$

**El signo elige la configuración del brazo** (hay dos soluciones para el mismo punto, ver sección 6). El script usa el signo `+`.

### Paso 5 — $\theta_2$

Se usa `atan2` (no `acos`), porque conserva el signo y el cuadrante:

$$\theta_2 = \mathrm{atan2}(\sin\theta_2,\ \cos\theta_2)$$

```matlab
theta2 = atan2(sen_theta2, cos_theta2);
```

$$\theta_2 = \mathrm{atan2}(0.75471,\ 0.65606) = \mathbf{49.0001^\circ}$$

### Paso 6 — $\theta_1 = \alpha - \varphi$

$\alpha$ es el ángulo de la recta $b$ respecto a $x$, y $\varphi$ es lo que $l_1$ "se queda corto" respecto a esa recta por culpa del codo:

$$\alpha = \mathrm{atan2}(\rho_y,\ \rho_x) \qquad \varphi = \mathrm{atan2}\big(l_2\sin\theta_2,\ \ l_1 + l_2\cos\theta_2\big)$$

$$\theta_1 = \alpha - \varphi$$

```matlab
alpha  = atan2(Py, Px);
phi    = atan2(l2*sen_theta2, l1 + l2*cos_theta2);
theta1 = alpha - phi;
```

$$\alpha = \mathrm{atan2}(25.5112,\ 13.5513) = 62.0232^\circ$$

$$\varphi = \mathrm{atan2}(12.2185,\ 26.1755) = 25.0232^\circ$$

$$\theta_1 = 62.0232^\circ - 25.0232^\circ = \mathbf{37.0000^\circ}$$

> **El orden importa:** $\theta_1$ depende de $\theta_2$ (por $\varphi$), así que **$\theta_2$ se calcula primero**.

### Paso 7 — $d_3$ (independiente del plano)

De la cinemática directa, $p_z = h_1+h_2+h_3-h_4-d_3$. Se despeja:

$$d_3 = h_1+h_2+h_3-h_4-p_z$$

```matlab
d3 = h1 + h2 + h3 - h4 - Pz;
```

$$d_3 = 12.57 + 0.87 + 0.41 - 5.40 - 8.45 = \mathbf{0.00 \text{ cm}}$$

Rango de $p_z$ alcanzable con la carrera de la prismática, $d_3\in[0,\,5.4]$ cm:

$$p_z = 8.45 - d_3 \ \Rightarrow\ p_z\in[3.05,\ 8.45]\ \text{cm}$$

Ambos puntos de prueba están en $p_z=8.45$, que es la posición más alta del efector ($d_3=0$).

### Paso 8 — Asignar a los joints del toolbox

<div align="center">

| Script | Asignación |
|---|---|
| `BASETRASL` | `q = [theta1, theta2, d3]` |
| `BASEREVOL` | `q = [0, theta1, theta2, d3]` |

</div>

### Salida en consola (punto B)

```text
theta2: 49.0001 deg
theta1: 37.0000 deg
d3: 0.0000 cm
```

---

## 5. Verificación con `fkine`

Se meten los valores calculados en el toolbox y se compara contra el punto objetivo:

```matlab
Robot.plot([q1,q2,q3], 'scale', 1.2, 'workspace', [-40 40 -40 40 -25 25]);
Robot.teach([q1,q2,q3])
Robot.fkine([q1,q2,q3])
```

Resultado para el punto B (ejecutado en MATLAB R2025b + RTB 10.4, ambos scripts dan lo mismo):

$$
T_4^0 =
\begin{bmatrix}
0.0698 & 0.9976 & 0 & \mathbf{14.6053} \\
0.9976 & -0.0698 & 0 & \mathbf{25.5112} \\
0 & 0 & -1 & \mathbf{8.4500} \\
0 & 0 & 0 & 1
\end{bmatrix}
$$

- La **última columna** coincide con el punto objetivo $(14.6053,\ 25.5112,\ 8.450)$. ✅
- La submatriz de rotación coincide con la forma teórica de la cinemática directa, con $\theta_1+\theta_2 = 86^\circ$: $\cos 86^\circ = 0.0698$ y $\sin 86^\circ = 0.9976$.
- El $-1$ en $z$ confirma que el eje del efector apunta **hacia abajo**.

<p align="center">
  Robot SCARA en el toolbox para el punto B
</p>

---

## 6. La segunda solución (codo opuesto)

Para el mismo punto objetivo existe otra configuración: se cambia el signo de $\sin\theta_2$.

```matlab
sen_theta2 = -sqrt(1 - cos_theta2^2);   % configuración opuesta
```

Como $\varphi$ también usa `sen_theta2`, **solo hay que cambiar esa línea**; $\theta_2$ y $\theta_1$ se ajustan solos.

<div align="center">

| Punto B | $\theta_1$ | $\theta_2$ | $d_3$ | `fkine` |
|---|---|---|---|---|
| $\sin\theta_2>0$ (script) | 37.0000° | +49.0001° | 0 | (14.6053, 25.5112, 8.45) |
| $\sin\theta_2<0$ | 87.0464° | −49.0001° | 0 | (14.6053, 25.5112, 8.45) |

</div>

Las dos llegan al **mismo punto**; solo cambia hacia qué lado "dobla" el codo. En el mundo real se elige según obstáculos o límites mecánicos de cada articulación.

---

## 7. Casos especiales

### 7.1 Brazo totalmente extendido — punto A (`BASEREVOL`)

Punto: $p_x=32.7980,\ p_y=0,\ p_z=8.45$.

$$\rho_x = 32.798-1.054 = 31.744 = l_1+l_2 \ \Rightarrow\ b = l_1 + l_2$$

Entonces $\cos\theta_2 = 1$, $\sin\theta_2 = 0$ y el resultado es:

```text
theta2: 0.0000 deg
theta1: 0.0000 deg
d3: 0.0000 cm
```

Es el **borde del espacio de trabajo**: el brazo queda estirado sobre el eje $x$ y es una **singularidad**, porque las dos configuraciones de codo (sección 6) **coinciden** en una sola. Aquí la protección `max(-1, min(1, ...))` es la que evita que el programa falle por un coseno apenas mayor que 1.

`fkine` devuelve $(32.7980,\ 0,\ 8.4500)$, es decir el punto pedido. ✅

<p align="center">
  Robot SCARA estirado — punto A
</p>

### 7.2 Punto fuera del alcance

Si $b > l_1+l_2 = 31.744$ cm (o $b < |l_1-l_2| = 0.636$ cm), el punto **no existe** para este robot. Con el `max/min` el script **no marca error**: satura el coseno y devuelve el ángulo del punto alcanzable más cercano, así que el `fkine` **no** coincidirá con el punto pedido. Siempre conviene comprobar:

```matlab
if b > l1 + l2 || b < abs(l1 - l2)
    warning('El punto está fuera del espacio de trabajo');
end
```

### 7.3 Límite de la prismática

Si el $d_3$ calculado queda fuera de $[0,\,5.4]$ cm, el punto es alcanzable en el plano pero no en altura. `teach` no deja llevar el slider fuera de `qlim`.

---

## 8. Resumen

<div align="center">

| Variable | Fórmula | En MATLAB |
|---|---|---|
| $\rho_x$ | $p_x - r_1$ | `Px = Pxd - r1;` |
| $b$ | $\sqrt{\rho_x^2+\rho_y^2}$ | `b = sqrt(Px^2 + Py^2);` |
| $\cos\theta_2$ | $\dfrac{b^2-l_1^2-l_2^2}{2l_1l_2}$ | `cos_theta2 = (b^2-l1^2-l2^2)/(2*l1*l2);` |
| $\sin\theta_2$ | $\pm\sqrt{1-\cos^2\theta_2}$ | `sen_theta2 = sqrt(1-cos_theta2^2);` |
| $\theta_2$ | $\mathrm{atan2}(\sin\theta_2,\cos\theta_2)$ | `theta2 = atan2(sen_theta2, cos_theta2);` |
| $\alpha$ | $\mathrm{atan2}(\rho_y,\rho_x)$ | `alpha = atan2(Py, Px);` |
| $\varphi$ | $\mathrm{atan2}(l_2\sin\theta_2,\ l_1+l_2\cos\theta_2)$ | `phi = atan2(l2*sen_theta2, l1+l2*cos_theta2);` |
| $\theta_1$ | $\alpha-\varphi$ | `theta1 = alpha - phi;` |
| $d_3$ | $h_1+h_2+h_3-h_4-p_z$ | `d3 = h1+h2+h3-h4-Pz;` |

</div>

Orden de cálculo: **$\rho$ → $b$ → $\theta_2$ → $\theta_1$ → $d_3$** → `fkine` para verificar.

---

## 9. Errores comunes

1. **Olvidar descontar $r_1$** en $p_x$: todo el resultado queda desplazado.
2. **Mal orden de joints en `BASEREVOL`:** hay que pasar `[0, θ1, θ2, d3]`, no `[θ1, θ2, d3]`.
3. **Usar `acos`/`atan` en vez de `atan2`:** se pierde el signo y el cuadrante (sale una solución errónea para $y<0$ o $\rho_x<0$).
4. **Quitar el `max/min` del coseno:** aparecen ángulos complejos en el borde del espacio de trabajo.
5. **Quitar el `'offset', h4` de la prismática:** el eje $z$ quedaría $h_4$ más alto de lo real.
6. **Mezclar unidades:** todo el modelo está en **cm**; si se pasan metros, `d3` y las posiciones salen mal.
7. **No haber ejecutado `startup_rvc`:** MATLAB dará error en `Link`/`SerialLink` (*"Undefined function"*).

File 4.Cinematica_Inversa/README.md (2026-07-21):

# Cinemática Inversa del Robot SCARA

Este documento desarrolla la **cinemática inversa** del robot SCARA: dado un punto deseado del efector final $(p_x, p_y, p_z)$, se busca calcular las variables articulares $\theta_1$, $\theta_2$ y $d_3$ necesarias para alcanzarlo.

La estrategia usada es **desacoplamiento geométrico**: como el robot es un SCARA, el movimiento se separa en dos problemas independientes que se resuelven por separado y luego se combinan:

1. Un problema **planar** (en $x,y$) para hallar $\theta_1$ y $\theta_2$, resuelto con geometría de triángulos (ley de cosenos).
2. Un problema **de una sola variable** (en $z$) para hallar $d_3$, resuelto despejando directamente de la ecuación de posición vertical.

Esta separación es posible porque, como se vio en la cinemática directa, la altura del efector final ($p_z$) depende **únicamente** de $d_3$ y de constantes del robot, mientras que $p_x$ y $p_y$ dependen **únicamente** de $\theta_1$ y $\theta_2$.

---

## 0. Planteamiento del problema

<p align="center">
  Vista general del SCARA
</p>

Se parte de un punto objetivo $(p_x, p_y, p_z)$ para el efector final, en el mismo sistema de referencia $\{0\}$ usado en la cinemática directa. El robot conserva la misma geometría vista antes: offset de base $r_1$, eslabones $l_1$ y $l_2$, alturas $h_1$–$h_4$, y articulación prismática $d_3$.

---

## 1. Reducción al plano de trabajo

<p align="center">
  Vista superior general del SCARA
</p>

Vista desde arriba (plano $xy$), donde se aprecia cómo $\theta_1$ y $\theta_2$ determinan la posición del efector final. Para simplificar el problema, se trabaja con las coordenadas del punto objetivo **relativas al origen del sistema $\{1\}$** (es decir, ya descontado el offset fijo $r_1$ de la base):

$$\rho_x = p_x - r_1 \qquad \rho_y = p_y$$

De aquí en adelante, $\rho_x$ y $\rho_y$ son los catetos del triángulo que se usa para resolver $\theta_1$ y $\theta_2$. El cálculo de $\theta_1$, $\theta_2$ es completamente independiente del de $d_3$ (sección 4).

---

## 2. Cálculo de $\theta_2$ (ley de cosenos)

### 2.1 Construcción del triángulo

Se traza la línea recta $b$ desde el origen de $\{1\}$ hasta el punto objetivo (efector final). Junto con los eslabones $l_1$ y $l_2$, esta línea forma un triángulo:

<p align="center">
  Trazado de la línea b hacia el efector final
</p>

Aislando el triángulo de lados $l_1$, $l_2$ y $b$:

<p align="center">
  Triángulo formado por l1, l2 y b
</p>

El ángulo interno del triángulo opuesto a $b$ es $\beta$. Por la geometría del mecanismo, $\beta$ y $\theta_2$ son ángulos suplementarios:

<p align="center">
  Relación entre beta y theta2
</p>

$$\beta + \theta_2 = 180^\circ \quad\Rightarrow\quad \beta = 180^\circ - \theta_2$$

Aplicando **ley de cosenos** en el triángulo:

$$b^2 = l_2^2 + l_1^2 - 2\,l_1 l_2 \cos(\beta)$$

### 2.2 Distancia $b$ al punto objetivo

<p align="center">
  Triángulo rectángulo con rho_x, rho_y y b
</p>

Del triángulo rectángulo formado por $\rho_x$, $\rho_y$ y $b$:

$$b = \sqrt{\rho_x^2 + \rho_y^2}$$

### 2.3 Despeje de $\theta_2$

Sustituyendo $\beta = 180^\circ-\theta_2$ y usando $\cos(180^\circ-\theta_2) = -\cos(\theta_2)$:

$$b^2 = l_2^2 + l_1^2 - 2\,l_1 l_2 \cos(180^\circ-\theta_2) = l_2^2 + l_1^2 + 2\,l_1 l_2 \cos(\theta_2)$$

Despejando el coseno:

$$\cos(\theta_2) = \frac{b^2 - l_1^2 - l_2^2}{2\,l_1 l_2}$$

Y usando la identidad $\sin^2(\theta_2)+\cos^2(\theta_2)=1$:

$$\sin(\theta_2) = \pm\sqrt{1-\left(\frac{b^2-l_1^2-l_2^2}{2\,l_1 l_2}\right)^2}$$

Dividiendo seno entre coseno para obtener la tangente, y despejando $\theta_2$:

$$
\boxed{
\theta_2 = \arctan\left(
\dfrac{\pm\sqrt{1-\left(\dfrac{b^2-l_1^2-l_2^2}{2\,l_1 l_2}\right)^2}\;\cdot\;2\,l_1 l_2}
{b^2-l_1^2-l_2^2}
\right)
}
$$

> **Sobre el signo $\pm$:** el radical de $\sin(\theta_2)$ tiene dos soluciones válidas. Físicamente corresponden a las dos configuraciones posibles del brazo para alcanzar el mismo punto: **codo arriba** y **codo abajo**. Elegir el signo `+` o `-` selecciona cuál de las dos configuraciones adopta el robot.

---

## 3. Cálculo de $\theta_1$ (triángulos auxiliares)

### 3.1 Ángulos $\alpha$ y $\varphi$

<p align="center">
  Ángulos alpha y phi respecto a theta1
</p>

Se definen dos ángulos auxiliares que, combinados, dan $\theta_1$:

- $\alpha$: ángulo entre el eje $x_0$ y la línea $b$ (línea recta hacia el punto objetivo).
- $\varphi$: ángulo entre la línea $b$ y el eslabón $l_1$.

De la geometría se cumple:

$$\alpha = \theta_1 + \varphi \quad\Rightarrow\quad \theta_1 = \alpha - \varphi$$

Por definición de tangente en el triángulo rectángulo formado por $\rho_x$, $\rho_y$ y $b$:

$$\tan(\alpha) = \frac{\rho_y}{\rho_x} \quad\Rightarrow\quad \alpha = \arctan\left(\frac{\rho_y}{\rho_x}\right)$$

### 3.2 Proyección del eslabón $l_2$

<p align="center">
  Proyección de l2 sobre la dirección de l1
</p>

Se proyecta el eslabón $l_2$ sobre la dirección de $l_1$ (componente $m$) y sobre su perpendicular (componente $n$, definida de forma análoga a $m$):

$$m = l_2\cos(\theta_2) \qquad n = l_2\sin(\theta_2)$$

### 3.3 Distancia total $k$

<p align="center">
  Distancia total k = l1 + m
</p>

La distancia total en la dirección de $l_1$ es:

$$k = l_1 + m = l_1 + l_2\cos(\theta_2)$$

Y $\varphi$ es el ángulo cuya tangente relaciona $n$ y $k$:

$$\tan(\varphi) = \frac{n}{k} = \frac{l_2\sin(\theta_2)}{l_1+l_2\cos(\theta_2)} \quad\Rightarrow\quad \varphi = \arctan\left(\frac{l_2\sin(\theta_2)}{l_1+l_2\cos(\theta_2)}\right)$$

### 3.4 Despeje de $\theta_1$

Sustituyendo $\alpha$ y $\varphi$ en $\theta_1=\alpha-\varphi$:

$$
\boxed{
\theta_1 = \arctan\left(\dfrac{\rho_y}{\rho_x}\right) - \arctan\left(\dfrac{l_2\sin(\theta_2)}{l_1+l_2\cos(\theta_2)}\right)
}
$$

> **Nota práctica:** en una implementación real conviene usar la función `atan2(ρy, ρx)` en vez de `arctan(ρy/ρx)`, ya que `atan2` sí distingue en qué cuadrante está el punto objetivo (evita ambigüedades cuando $\rho_x$ es negativo o cero).

---

## 4. Cálculo de $d_3$ (componente vertical)

De la cinemática directa (matriz $T_4^0$) se obtuvo que la altura del efector final es:

$$p_z = h_1+h_2+h_3-h_4-d_3$$

Como esta ecuación depende **únicamente** de $d_3$ (todo lo demás son constantes fijas del robot), se despeja directamente:

$$
\boxed{
d_3 = h_1+h_2+h_3-h_4-p_z
}
$$

---

## 5. Solución completa de la cinemática inversa

<div align="center">

| Variable | Fórmula |
|---|---|
| $\rho_x,\ \rho_y$ | $\rho_x = p_x - r_1,\quad \rho_y = p_y$ |
| $b$ | $b=\sqrt{\rho_x^2+\rho_y^2}$ |
| $\theta_2$ | $\theta_2=\arctan\!\left(\dfrac{\pm\sqrt{1-\left(\frac{b^2-l_1^2-l_2^2}{2l_1l_2}\right)^2}\cdot 2l_1l_2}{b^2-l_1^2-l_2^2}\right)$ |
| $\theta_1$ | $\theta_1=\arctan\!\left(\dfrac{\rho_y}{\rho_x}\right)-\arctan\!\left(\dfrac{l_2\sin\theta_2}{l_1+l_2\cos\theta_2}\right)$ |
| $d_3$ | $d_3=h_1+h_2+h_3-h_4-p_z$ |

</div>

Dado un punto objetivo $(p_x,p_y,p_z)$, el orden de cálculo es:

1. Calcular $\rho_x, \rho_y$ y $b$.
2. Calcular $\theta_2$ (eligiendo signo según configuración deseada: codo arriba o codo abajo).
3. Calcular $\theta_1$ usando el $\theta_2$ obtenido.
4. Calcular $d_3$ de forma independiente, directamente desde $p_z$.

---

## 6. Verificación de consistencia

Un punto objetivo alcanzable por el robot tiene, en general, **dos soluciones válidas** (codo arriba / codo abajo) debido al signo $\pm$ en $\theta_2$, y **una única solución** para $d_3$, ya que la articulación prismática no tiene ambigüedad de configuración.

Como prueba de consistencia del modelo, si se toman los valores de $\theta_1$, $\theta_2$ y $d_3$ obtenidos aquí y se sustituyen en la matriz $T_4^0$ de la [cinemática directa](../3.Cinematica_Directa/README.md), se debe recuperar exactamente el punto objetivo $(p_x,p_y,p_z)$ del que se partió — cerrando así el ciclo directa ⇄ inversa.

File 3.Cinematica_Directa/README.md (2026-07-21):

# Cinemática Directa del Robot SCARA

Este documento desarrolla la **cinemática directa** del robot SCARA del proyecto, es decir, el cálculo de la posición y orientación del efector final respecto a la base, en función de las variables articulares del robot.

El robot cuenta con **3 grados de libertad activos**:

<div align="center">

| Articulación | Tipo | Variable |
|---|---|---|
| 1 | Rotacional | $\theta_1$ |
| 2 | Rotacional | $\theta_2$ |
| 3 | Prismática | $d_3$ |

</div>

Para comprobar la consistencia del modelo, la cinemática directa se resolvió por **dos métodos independientes**:

1. **Matrices de Transformación Homogénea (MTH)** — construidas "a mano" analizando cada desplazamiento y rotación entre sistemas de referencia consecutivos.
2. **Denavit–Hartenberg (DH)** — usando la tabla de parámetros estándar y la matriz genérica $A_i$.

Como se muestra al final, **ambos métodos arrojan exactamente la misma matriz final**, lo que confirma que la asignación de sistemas de referencia y el modelo geométrico del robot son correctos.

---

## 0. Vistas del robot y sistemas de referencia

Antes de entrar en las matrices, estas dos vistas muestran cómo se ubicaron los sistemas de referencia $\{0\},\{1\},\{2\},\{3\},\{4\}$ sobre el robot y de dónde salen físicamente cada uno de los parámetros ($r_1$, $l_1$, $l_2$, $h_1$–$h_4$, $d_3$, $\theta_1$, $\theta_2$) usados en las matrices.

### Vista general (isométrica)

<p align="center">
  Vista general del SCARA con sistemas de referencia
</p>

Aquí se ve la cadena completa de eslabones desde la base ($\{0\}$) hasta el efector final ($\{4\}$):

- $\{0\}$ está en la base, elevado una altura $h_1$ y desplazado $r_1$ respecto al punto de apoyo.
- $\{1\}$ es el origen de la primera articulación rotacional ($\theta_1$), a una altura adicional $h_2$.
- $\{2\}$ es el origen de la segunda articulación rotacional ($\theta_2$), separado de $\{1\}$ por el eslabón $l_1$ y a una altura $h_3$.
- $\{3\}$ está al final del eslabón $l_2$, en la base de la articulación prismática.
- $\{4\}$ es el sistema del efector final, desplazado verticalmente por $d_3$ (variable) y $h_4$ (fijo) respecto a $\{3\}$.

Esta vista es la que sustenta directamente las traslaciones y rotaciones usadas en las matrices $T_1^0, T_2^1, T_3^2, T_4^3$ (y sus equivalentes DH $A_1, A_2, A_3, A_4$) de las secciones 1 y 2.

### Vista superior (plano XY)

<p align="center">
  Vista superior del SCARA — plano de trabajo
</p>

Esta vista, tomada desde arriba, muestra el plano en el que realmente se mueve el efector final (el eje $z$ queda "de frente" al lector). Aquí se aprecia con claridad la construcción geométrica que da origen a las componentes $p_x$ y $p_y$ de la posición final:

- El eslabón $l_1$, rotado un ángulo $\theta_1$ respecto al eje $x_0$, se proyecta sobre los ejes como $l_1\cos\theta_1$ (horizontal) y $l_1\sin\theta_1$ (vertical).
- El eslabón $l_2$, rotado un ángulo adicional $\theta_2$ respecto a $x_1$ (medido desde el eje $x_2$, solidario al primer eslabón), se proyecta como $l_2\cos\theta_2$ y $l_2\sin\theta_2$ en el sistema $\{2\}$.
- Sumando vectorialmente ambas proyecciones, más el desfase inicial $r_1$, se obtiene directamente:

$$p_x = r_1 + l_1\cos\theta_1 + l_2\cos(\theta_1+\theta_2)$$
$$p_y = l_1\sin\theta_1 + l_2\sin(\theta_1+\theta_2)$$

Estas dos expresiones son exactamente las que aparecen en la última columna de la matriz $T_4^0$ obtenida en las secciones 1 y 2 — es decir, esta vista superior es una forma **geométrica/intuitiva** de llegar al mismo resultado que se obtuvo algebraicamente multiplicando matrices, y sirve como tercera verificación cruzada del modelo.

---

## 1. Método 1: Matrices de Transformación Homogénea (MTH)

La idea de este método es recorrer la cadena cinemática eslabón por eslabón, y en cada tramo preguntarse: *"¿qué rotación y qué traslación hay entre el sistema $i-1$ y el sistema $i$?"*. Cada respuesta se traduce en una matriz homogénea $4\times4$, y la transformación total es el producto de todas ellas:

$$
T_4^0 = T_1^0 \cdot T_2^1 \cdot T_3^2 \cdot T_4^3
$$

### Tramo 0 → 1 ($T_1^0$)

Del sistema base al sistema 1 solo hay traslación pura: una separación $r_1$ en $x$ y una altura $h_1$ en $z$ (no hay rotación entre estos dos ejes).

$$
T_1^0 =
\begin{bmatrix}
1 & 0 & 0 & r_1 \\
0 & 1 & 0 & 0 \\
0 & 0 & 1 & h_1 \\
0 & 0 & 0 & 1
\end{bmatrix}
$$

### Tramo 1 → 2 ($T_2^1$)

Aquí aparece la primera articulación rotacional $\theta_1$ (rotación en torno a $z$), combinada con una traslación de $l_1$ a lo largo del nuevo eje $x$ y una altura $h_2$ en $z$:

$$
T_2^1 =
\begin{bmatrix}
\cos\theta_1 & -\sin\theta_1 & 0 & l_1\cos\theta_1 \\
\sin\theta_1 & \cos\theta_1 & 0 & l_1\sin\theta_1 \\
0 & 0 & 1 & h_2 \\
0 & 0 & 0 & 1
\end{bmatrix}
$$

### Tramo 2 → 3 ($T_3^2$)

Segunda articulación rotacional $\theta_2$. A diferencia del tramo anterior, aquí el sistema 3 está **girado 180° respecto a $x$** (por eso aparece el $-1$ en la componente $z$ y los signos cambiados en la segunda fila/columna: $R_z(\theta_2)\cdot R_x(180°)$). También hay traslación $l_2$ en $x$ y $h_3$ en $z$:

$$
T_3^2 =
\begin{bmatrix}
\cos\theta_2 & \sin\theta_2 & 0 & l_2\cos\theta_2 \\
\sin\theta_2 & -\cos\theta_2 & 0 & l_2\sin\theta_2 \\
0 & 0 & -1 & h_3 \\
0 & 0 & 0 & 1
\end{bmatrix}
$$

### Tramo 3 → 4 ($T_4^3$)

Tramo final, correspondiente a la articulación prismática. No hay rotación, solo una traslación vertical dada por la suma de la altura fija $h_4$ más el desplazamiento variable $d_3$:

$$
T_4^3 =
\begin{bmatrix}
1 & 0 & 0 & 0 \\
0 & 1 & 0 & 0 \\
0 & 0 & 1 & d_3 + h_4 \\
0 & 0 & 0 & 1
\end{bmatrix}
$$

> **Nota:** en el desarrollo a mano esta última matriz quedó rotulada como $T_1^0$ por error de transcripción; en realidad corresponde a $T_4^3$, que es la que se usa en el producto final.

### Resultado del producto $T_4^0$

Multiplicando las cuatro matrices en orden, y usando las identidades trigonométricas de suma de ángulos ($\cos\theta_1\cos\theta_2 - \sin\theta_1\sin\theta_2 = \cos(\theta_1+\theta_2)$, etc.), se llega a:

$$
T_4^0 =
\begin{bmatrix}
\cos(\theta_1+\theta_2) & \sin(\theta_1+\theta_2) & 0 & l_1\cos\theta_1 + l_2\cos(\theta_1+\theta_2) + r_1 \\
\sin(\theta_1+\theta_2) & -\cos(\theta_1+\theta_2) & 0 & l_1\sin\theta_1 + l_2\sin(\theta_1+\theta_2) \\
0 & 0 & -1 & h_1+h_2+h_3-h_4-d_3 \\
0 & 0 & 0 & 1
\end{bmatrix}
$$

---

## 2. Método 2: Denavit–Hartenberg (DH)

El método DH es más sistemático: en lugar de "pensar" geométricamente cada tramo, se sigue una convención fija de 4 parámetros por eslabón ($\theta_i$, $d_i$, $\alpha_i$, $a_i$) obtenidos a partir de reglas de asignación de ejes.

### 2.1 Asignación de sistemas de referencia

Para cada eslabón se definieron los ejes $z_i$ y $x_i$ siguiendo la convención estándar:

**Ejes $z_i$** (eje de cada articulación):

<div align="center">

| $i$ | Regla | Resultado |
|---|---|---|
| 1 | $x_{i-1} = x_0 \Rightarrow x_i = x_1$, con $z_0$ fijo | Distancia respecto a $z_0$: $h_1$ |
| 2 | $x_{i-1}=x_1 \Rightarrow x_i=x_2$, con $z_1$ fijo | Distancia respecto a $z_1$: $h_2$ |
| 3 | $x_{i-1}=x_2 \Rightarrow x_i=x_3$, con $z_2$ fijo | Distancia respecto a $z_2$: $h_3$ |
| 4 | $x_{i-1}=x_3 \Rightarrow x_i=x_4$, con $z_3$ fijo | Distancia respecto a $z_3$: $h_4+d_3$ |

</div>

**Ejes $x_i$** (perpendicular común entre $z_{i-1}$ y $z_i$):

<div align="center">

| $i$ | Regla | Resultado |
|---|---|---|
| 1 | $z_{i-1}=z_0 \Rightarrow z_i=z_1$, con $x_1$ fijo | Distancia respecto a $x_1$: $r_1$ |
| 2 | $z_{i-1}=z_1 \Rightarrow z_i=z_2$, con $x_2$ fijo | Distancia respecto a $x_2$: $l_1$ |
| 3 | $z_{i-1}=z_2 \Rightarrow z_i=z_3$, con $x_3$ fijo (ángulo $\pi$ entre ejes) | Distancia respecto a $x_3$: $l_2$ |
| 4 | $z_{i-1}=z_3 \Rightarrow z_i=z_4$, con $x_4$ fijo | Distancia respecto a $x_4$: $0$ |

</div>

### 2.2 Tabla de parámetros DH

<div align="center">

| $i$ | $\theta_i$ | $d_i$ | $\alpha_i$ | $a_i$ |
|---|---|---|---|---|
| 1 | $0$ | $h_1$ | $0$ | $r_1$ |
| 2 | $\theta_1$ | $h_2$ | $0$ | $l_1$ |
| 3 | $\theta_2$ | $h_3$ | $\pi$ | $l_2$ |
| 4 | $0$ | $h_4+d_3$ | $0$ | $0$ |

</div>

Variables articulares del robot:

$$q_1=\theta_1 \qquad q_2=\theta_2 \qquad q_3=d_3$$

### 2.3 Matriz genérica $A_i$

Cada fila de la tabla se convierte en una matriz homogénea usando la fórmula estándar de Denavit–Hartenberg:

$$
A_i =
\begin{bmatrix}
\cos\theta_i & -\sin\theta_i\cos\alpha_i & \sin\theta_i\sin\alpha_i & a_i\cos\theta_i \\
\sin\theta_i & \cos\theta_i\cos\alpha_i & -\cos\theta_i\sin\alpha_i & a_i\sin\theta_i \\
0 & \sin\alpha_i & \cos\alpha_i & d_i \\
0 & 0 & 0 & 1
\end{bmatrix}
$$

### 2.4 Matrices individuales

**$A_1$** ($\theta_1=0,\ d_1=h_1,\ \alpha_1=0,\ a_1=r_1$):

$$
A_1 =
\begin{bmatrix}
1 & 0 & 0 & r_1 \\
0 & 1 & 0 & 0 \\
0 & 0 & 1 & h_1 \\
0 & 0 & 0 & 1
\end{bmatrix}
$$

**$A_2$** ($\theta_2=\theta_1,\ d_2=h_2,\ \alpha_2=0,\ a_2=l_1$):

$$
A_2 =
\begin{bmatrix}
\cos\theta_1 & -\sin\theta_1 & 0 & l_1\cos\theta_1 \\
\sin\theta_1 & \cos\theta_1 & 0 & l_1\sin\theta_1 \\
0 & 0 & 1 & h_2 \\
0 & 0 & 0 & 1
\end{bmatrix}
$$

**$A_3$** ($\theta_3=\theta_2,\ d_3=h_3,\ \alpha_3=\pi,\ a_3=l_2$). Al evaluar $\cos\pi=-1$ y $\sin\pi=0$:

$$
A_3 =
\begin{bmatrix}
\cos\theta_2 & \sin\theta_2 & 0 & l_2\cos\theta_2 \\
\sin\theta_2 & -\cos\theta_2 & 0 & l_2\sin\theta_2 \\
0 & 0 & -1 & h_3 \\
0 & 0 & 0 & 1
\end{bmatrix}
$$

**$A_4$** ($\theta_4=0,\ d_4=h_4+d_3,\ \alpha_4=0,\ a_4=0$):

$$
A_4 =
\begin{bmatrix}
1 & 0 & 0 & 0 \\
0 & 1 & 0 & 0 \\
0 & 0 & 1 & h_4+d_3 \\
0 & 0 & 0 & 1
\end{bmatrix}
$$

### 2.5 Producto final

$$
T_4^0 = A_1 \cdot A_2 \cdot A_3 \cdot A_4
$$

---

## 3. Comparación de resultados

Nótese que **$A_1=T_1^0$**, **$A_2=T_2^1$**, **$A_3=T_3^2$** y **$A_4=T_4^3$** son idénticas matriz a matriz entre ambos métodos. Esto no es casualidad: significa que la asignación de ejes hecha "intuitivamente" en el método MTH coincide exactamente con la que exige la convención formal de Denavit-Hartenberg.

Como consecuencia, el producto final es el mismo por los dos caminos:

$$
T_4^0 =
\begin{bmatrix}
\cos(\theta_1+\theta_2) & \sin(\theta_1+\theta_2) & 0 & l_1\cos\theta_1 + l_2\cos(\theta_1+\theta_2) + r_1 \\
\sin(\theta_1+\theta_2) & -\cos(\theta_1+\theta_2) & 0 & l_1\sin\theta_1 + l_2\sin(\theta_1+\theta_2) \\
0 & 0 & -1 & h_1+h_2+h_3-h_4-d_3 \\
0 & 0 & 0 & 1
\end{bmatrix}
$$

De esta matriz se puede leer directamente:

- **Posición del efector final** (última columna):
  - $p_x = l_1\cos\theta_1 + l_2\cos(\theta_1+\theta_2) + r_1$
  - $p_y = l_1\sin\theta_1 + l_2\sin(\theta_1+\theta_2)$
  - $p_z = h_1+h_2+h_3-h_4-d_3$
- **Orientación del efector final** (submatriz $3\times3$ superior izquierda): rotación neta $\theta_1+\theta_2$ en torno a $z$, combinada con la inversión de $z$ heredada del giro de 180° introducido en el eslabón 3.

## 4. Conclusión

Obtener la **misma matriz $T_4^0$** por MTH y por DH confirma que:

1. La geometría del robot (longitudes $l_1$, $l_2$, alturas $h_1$–$h_4$, offset $r_1$) fue interpretada correctamente en ambos métodos.
2. La orientación de los ejes en cada sistema de referencia es consistente.
3. El modelo de cinemática directa está listo para usarse como base de la **cinemática inversa** (siguiente sección de este repositorio), ya que las ecuaciones de posición ($p_x, p_y, p_z$) obtenidas aquí son el punto de partida para despejar $\theta_1$, $\theta_2$ y $d_3$ en función de una posición deseada del efector final.

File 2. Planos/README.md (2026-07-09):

# 2. Planos

Esta carpeta contiene los planos técnicos del robot SCARA, generados a partir de las piezas de SolidWorks (`.SLDDRW`), junto con su versión exportada en PDF.

## Convención de ejes

La asignación de los ejes de referencia se realizó siguiendo la convención de un sistema cartesiano de mano derecha. El eje X se orientó hacia el frente del manipulador (dirección del efector final), el eje Z se estableció en la dirección vertical positiva y el eje Y quedó determinado por la regla de la mano derecha.

## Sistema de nomenclatura

Los archivos siguen el formato `[Prefijo]-[Código]_[Nombre].[Extensión]`, usando los mismos códigos de elemento definidos en la carpeta [`1. Piezas y Ensambles SolidWorks`](../1.%20Piezas%20y%20Ensambles%20SolidWorks) para que sea fácil relacionar cada plano con su pieza correspondiente.

<div align="center">

| Prefijo | Significado |
|---|---|
| `PLN-` | Plano en SolidWorks (`.SLDDRW`) |
| `PDF-` | Versión exportada en PDF del mismo plano |

</div>

<div align="center">

| Código | Elemento |
|---|---|
| `00` | Base fija |
| `01` | Eslabón 1 |
| `02` | Eslabón 2 |
| `03` | Piñón |
| `04` | Cremallera |
| `05` | Tapa de eslabón |
| `06` | Soporte del servo |
| `08` | Ensamblaje completo del robot |

</div>

## Contenido

<div align="center">

| Archivo | Descripción |
|---|---|
| `PLN-00_BaseFija.SLDDRW` | Plano de la base fija (pieza sin servomotor). |
| `PLN-01_Eslabon1.SLDDRW` | Plano del eslabón 1 (pieza base, sin tapa, soporte ni servo). |
| `PLN-02_Eslabon2.SLDDRW` | Plano del eslabón 2 (pieza base, sin tapa, piñón ni servo). |
| `PLN-03_Piñon.SLDDRW` | Plano del piñón. |
| `PLN-04_Cremallera.SLDDRW` | Plano de la cremallera. |
| `PLN-05_TapaEslabon.SLDDRW` | Plano de la tapa usada en los eslabones. |
| `PLN-06_SoporteServo.SLDDRW` | Plano del soporte del servomotor. |
| `PLN-08_EnsambleCompleto.SLDDRW` | Plano general del ensamblaje completo del robot. |

</div>

## Carpeta `PDF/`

Contiene la exportación en PDF de cada uno de los planos anteriores (con el prefijo `PDF-` en lugar de `PLN-`), para consulta rápida sin necesidad de abrir SolidWorks.

## Notas

- Estos planos corresponden a las piezas **base** de cada elemento (sin tapa, sin soporte y sin servomotor), no a las versiones "Completo"/"ConServo" que se usan para la simulación en Matlab. Esas piezas están documentadas en la carpeta [`1. Piezas y Ensambles SolidWorks`](../1.%20Piezas%20y%20Ensambles%20SolidWorks).
- El código de cada plano coincide con el código de su pieza/ensamblaje correspondiente en la carpeta de Piezas y Ensambles, para facilitar la trazabilidad entre ambas carpetas.

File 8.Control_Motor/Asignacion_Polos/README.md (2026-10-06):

# Sintonización por Asignación de Polos (PI y PID)

En este método **no se prueban reglas empíricas**: se escribe el polinomio característico del lazo cerrado en función de las ganancias del controlador, se **elige dónde se quieren los polos** y se igualan coeficientes para despejar $K_p$, $K_i$ y $K_d$.

Se diseñaron dos controladores para la misma planta del motor (ver la [visión general](../README.md)):

$$
G(s)=\frac{\theta(s)}{V(s)}=\frac{33792}{s^3+2500\,s^2+55822\,s}
$$

- **PID**: $\zeta=0.96$, $t_s=0.33$ s
- **PI**: $\zeta=0.97$, $t_s=0.36$ s

---

## 0. Contenido

<div align="center">

| Archivo | Descripción |
|---|---|
| `AsignacionPolos.slx` | Modelo Simulink con los dos lazos cerrados (PI y PID) |
| `images/` | Captura del modelo y figuras del diseño y la verificación |

</div>

<p align="center">
  Modelo Simulink AsignacionPolos
</p>

---

## 1. Lazo cerrado con el controlador PID

Se parte del lazo con realimentación unitaria:

<p align="center">
  Lazo cerrado con el controlador PID y la planta del motor
</p>

Se agrupa el controlador en una sola fracción y se multiplica por la planta:

$$
C(s)=K_p+\frac{K_i}{s}+K_d\,s=\frac{K_d\,s^2+K_p\,s+K_i}{s}
$$

$$
L(s)=C(s)\,G(s)=\frac{33792\,(K_d\,s^2+K_p\,s+K_i)}{s^2\,(s^2+2500\,s+55822)}
$$

El lazo cerrado es $T(s)=L(s)/(1+L(s))$, y su denominador es el **polinomio característico**:

$$
\boxed{\,s^4+2500\,s^3+(55822+33792\,K_d)\,s^2+33792\,K_p\,s+33792\,K_i\,}
$$

Dos cosas importantes de este polinomio:

1. Es de **cuarto orden** (los 3 polos de la planta + el integrador del controlador), así que hay **cuatro polos** que ubicar.
2. Los parámetros del controlador solo aparecen en los coeficientes de $s^2$, $s^1$ y $s^0$. El coeficiente de $s^3$ **siempre vale 2500**, sin importar $K_p$, $K_i$, $K_d$; es decir, la **suma de los cuatro polos queda fija en −2500**.

---

## 2. Diseño del PID
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

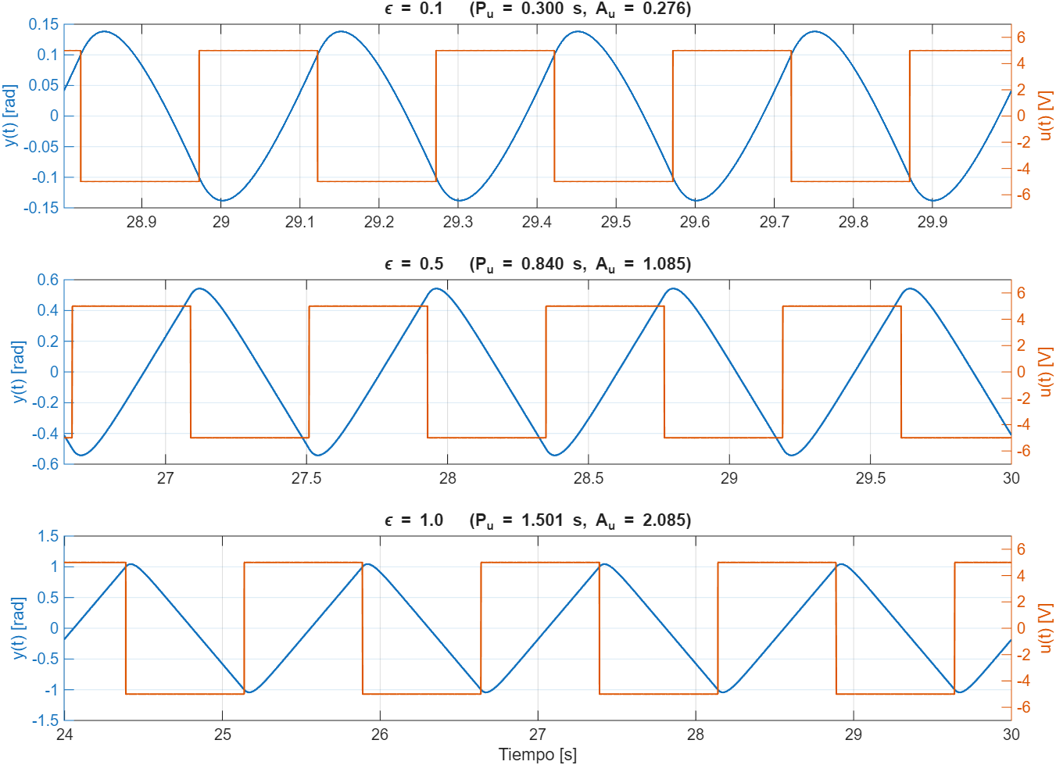
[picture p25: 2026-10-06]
8.Control_Motor/Metodo_Rele/images/rele_ciclo_limite.png

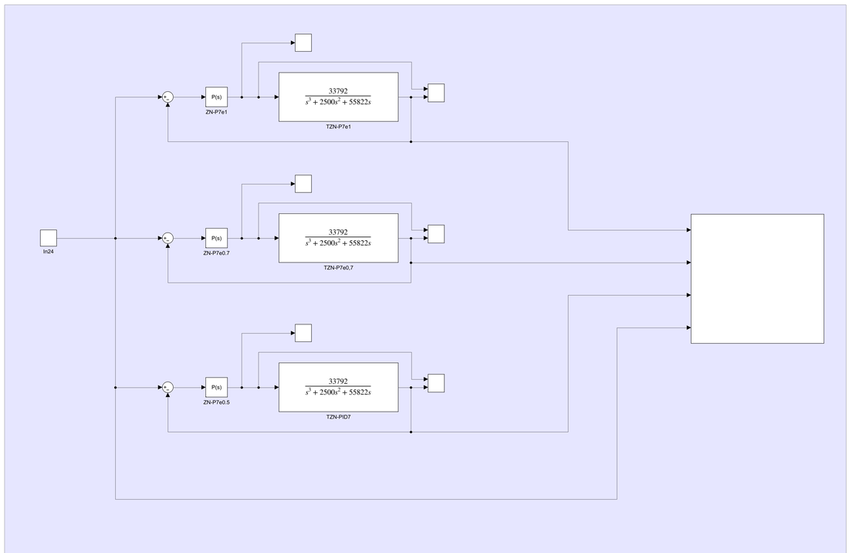
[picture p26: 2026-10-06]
8.Control_Motor/Metodo_Rele/images/panel_best3.png

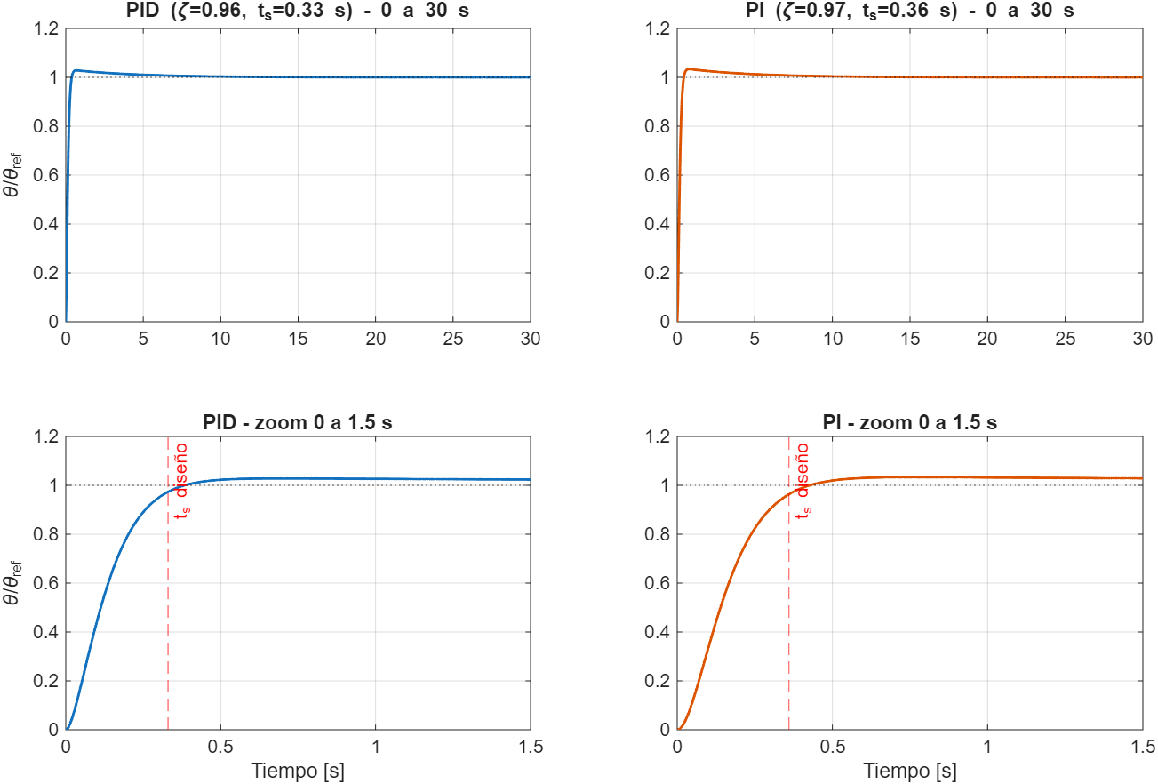
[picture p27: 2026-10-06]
8.Control_Motor/Asignacion_Polos/images/polos_escalon_unitario.png

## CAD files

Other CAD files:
1. Piezas y Ensambles SolidWorks/ASM-08_EnsambleCompleto.SLDASM
1. Piezas y Ensambles SolidWorks/ASM-03_Piñon_6Horn.SLDASM
1. Piezas y Ensambles SolidWorks/ASM-01_Eslabon1_ConServo.SLDASM
1. Piezas y Ensambles SolidWorks/ASM-07_ServoGenerico.SLDASM
1. Piezas y Ensambles SolidWorks/ASM-00_BaseFija_ConServo.SLDASM
1. Piezas y Ensambles SolidWorks/ASM-02_Eslabon2_ConServo.SLDASM
5. Matlab_Simscape/Parte3_Predeterminado_sldprt.STEP
7. URDF/ArchivosURDF/meshes/Cremallera.STL
1. Piezas y Ensambles SolidWorks/PZA-04_Cremallera.SLDPRT
5. Matlab_Simscape/Parte1_Predeterminado_sldprt.STEP
7. URDF/ArchivosURDF/meshes/Parte3.STL
1. Piezas y Ensambles SolidWorks/PZA-01_Eslabon1_Completo.SLDPRT
5. Matlab_Simscape/CremalleraDesde0_Predeterminado_sldprt.STEP
7. URDF/ArchivosURDF/meshes/BaseFija.STL
1. Piezas y Ensambles SolidWorks/PZA-00_BaseFija_ConServo.SLDPRT
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

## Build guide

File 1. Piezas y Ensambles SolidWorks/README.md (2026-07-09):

# 1. Piezas y Ensambles SolidWorks

Esta carpeta contiene todas las piezas (`.SLDPRT`) y ensamblajes (`.SLDASM`) del diseño CAD del robot SCARA.

## Convención de ejes

La asignación de los ejes de referencia se realizó siguiendo la convención de un sistema cartesiano de mano derecha. El eje X se orientó hacia el frente del manipulador (dirección del efector final), el eje Z se estableció en la dirección vertical positiva y el eje Y quedó determinado por la regla de la mano derecha.

Los orígenes de las piezas coinciden con el punto donde se aplican las relaciones de posición en el ensamblaje (por ejemplo, en la interfaz con el servomotor), para asegurar coherencia entre todas las piezas del sistema.

## Sistema de nomenclatura

Los archivos siguen el formato `[Prefijo]-[Código]_[Nombre]_[Estado].[Extensión]`:

**Prefijos:**

<div align="center">

| Prefijo | Significado |
|---|---|
| `PZA-` | Pieza individual |
| `ASM-` | Ensamblaje |

</div>

**Códigos por elemento:**

<div align="center">

| Código | Elemento |
|---|---|
| `00` | Base fija |
| `01` | Eslabón 1 |
| `02` | Eslabón 2 |
| `03` | Piñón |
| `04` | Cremallera |
| `05` | Tapa de eslabón |
| `06` | Soporte del servo |
| `07` | Servo horn / servo genérico |
| `08` | Ensamblaje completo del robot |

</div>

## Base fija

<div align="center">

| Archivo | Descripción |
|---|---|
| `PZA-00_BaseFija_SinServo.SLDPRT` | Cuerpo de la base fija, sin servomotor. |
| `PZA-00_BaseFija_ConServo.SLDPRT` | Base fija con servomotor integrado. Exportada como pieza única desde `ASM-00_BaseFija_ConServo.SLDASM` para simplificar el modelo de cara a Matlab. |
| `ASM-00_BaseFija_ConServo.SLDASM` | Ensamblaje de la base fija con su servomotor. |

</div>

## Eslabón 1

<div align="center">

| Archivo | Descripción |
|---|---|
| `PZA-01_Eslabon1_Base.SLDPRT` | Cuerpo del eslabón 1, sin tapa, sin soporte de servo y sin servo. |
| `PZA-01_Eslabon1_Completo.SLDPRT` | Eslabón 1 con tapa, soporte y servomotor integrados. Exportada como pieza única desde `ASM-01_Eslabon1_ConServo.SLDASM` para simplificar el modelo de cara a Matlab. |
| `ASM-01_Eslabon1_ConServo.SLDASM` | Ensamblaje del eslabón 1 con tapa, soporte y servomotor. |

</div>

## Eslabón 2

<div align="center">

| Archivo | Descripción |
|---|---|
| `PZA-02_Eslabon2_Base.SLDPRT` | Cuerpo del eslabón 2, sin tapa, sin piñón y sin servo. |
| `PZA-02_Eslabon2_Completo.SLDPRT` | Eslabón 2 con tapa, piñón y servomotor integrados. Exportada como pieza única desde `ASM-02_Eslabon2_ConServo.SLDASM` para simplificar el modelo de cara a Matlab. |
| `ASM-02_Eslabon2_ConServo.SLDASM` | Ensamblaje del eslabón 2 con tapa, piñón y servomotor. |

</div>

## Piñón

<div align="center">

| Archivo | Descripción |
|---|---|
| `PZA-03_Piñon.SLDPRT` | Piñón individual. |
| `PZA-03_Piñon_6Horn.SLDPRT` | Piñón con los 6 horns del servomotor integrados, exportado como pieza única desde `ASM-03_Piñon_6Horn.SLDASM`. |
| `ASM-03_Piñon_6Horn.SLDASM` | Ensamblaje del piñón con los 6 horns del servomotor. |

</div>

## Otros componentes

<div align="center">

| Archivo | Descripción |
|---|---|
| `PZA-04_Cremallera.SLDPRT` | Cremallera del sistema piñón-cremallera. |
| `PZA-05_TapaEslabon.SLDPRT` | Tapa usada en los eslabones. |
| `PZA-06_SoporteServo.SLDPRT` | Soporte del servomotor. |
| `PZA-07_ServoHorn.SLDPRT` | Servo horn individual. |
| `ASM-07_ServoGenerico.SLDASM` | Ensamblaje genérico del servomotor, sin la pieza a la que se acopla. |

</div>

## Ensamblaje completo

<div align="center">

| Archivo | Descripción |
|---|---|
| `ASM-08_EnsambleCompleto.SLDASM` | Ensamblaje completo del robot: base fija, eslabón 1, eslabón 2 y cremallera, usando las mínimas relaciones de posición posibles para mantener el modelo simple. |

</div>

## Notas de diseño

- Las piezas "Completo" / "ConServo" simplifican el modelo (reducen número de componentes y relaciones) para facilitar su exportación a Matlab.
- El ensamblaje completo busca usar el menor número de relaciones de posición posible, priorizando simplicidad sobre precisión de mating, ya que el objetivo es un modelo cinemático funcional y no una validación mecánica exhaustiva.

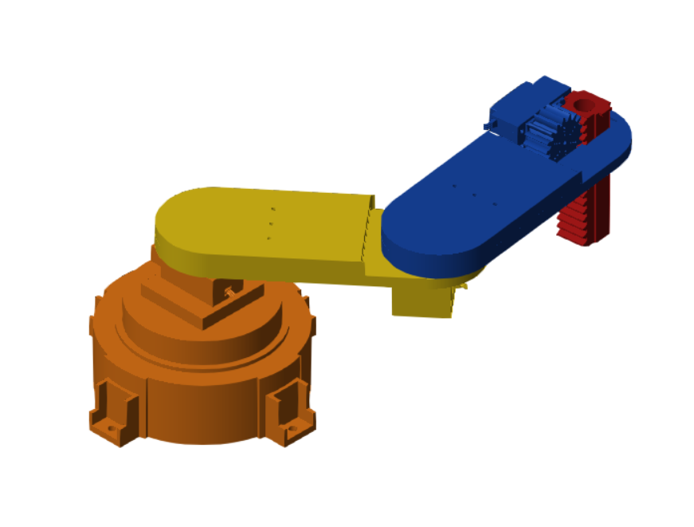
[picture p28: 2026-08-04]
5. Matlab_Simscape/ENSAMBLE.png

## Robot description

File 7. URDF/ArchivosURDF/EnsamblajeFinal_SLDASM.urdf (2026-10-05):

<?xml version="1.0" encoding="utf-8"?>
<!-- This URDF was automatically created by SolidWorks to URDF Exporter! Originally created by Stephen Brawner (brawner@gmail.com) 
     Commit Version: 1.6.0-4-g7f85cfe  Build Version: 1.6.7995.38578
     For more information, please see http://wiki.ros.org/sw_urdf_exporter -->
<robot name="EnsamblajeFinal.SLDASM">
  <link name="Parte1">
    <inertial>
      <origin xyz="1.2145E-05 1.2327E-10 0.035788" rpy="0 0 0" />
      <mass value="1.2446" />
      <inertia ixx="0.0022942" ixy="-1.5109E-13" ixz="-6.645E-09" iyy="0.0023004" iyz="-1.114E-12" izz="0.0032198" />
    </inertial>
    <visual>
      <origin xyz="0 0 0" rpy="0 0 0" />
      <geometry>
        <mesh filename="package://EnsamblajeFinal.SLDASM/meshes/Parte1.STL" />
      </geometry>
      <material name="">
        <color rgba="0.79216 0.81961 0.93333 1" />
      </material>
    </visual>
    <collision>
      <origin xyz="0 0 0" rpy="0 0 0" />
      <geometry>
        <mesh filename="package://EnsamblajeFinal.SLDASM/meshes/Parte1.STL" />
      </geometry>
    </collision>
  </link>
  <link name="Parte2">
    <inertial>
      <origin xyz="0.074781 -7.281E-06 -0.0014987" rpy="0 0 0" />
      <mass value="0.24392" />
      <inertia ixx="0.00012344" ixy="6.1822E-08" ixz="2.5441E-05" iyy="0.00075069" iyz="-2.4985E-09" izz="0.00085648" />
    </inertial>
    <visual>
      <origin xyz="0 0 0" rpy="0 0 0" />
      <geometry>
        <mesh filename="package://EnsamblajeFinal.SLDASM/meshes/Parte2.STL" />
      </geometry>
      <material name="">
        <color rgba="0.79216 0.81961 0.93333 1" />
      </material>
    </visual>
    <collision>
      <origin xyz="0 0 0" rpy="0 0 0" />
      <geometry>
        <mesh filename="package://EnsamblajeFinal.SLDASM/meshes/Parte2.STL" />
      </geometry>
    </collision>
  </link>
  <joint name="JointP2" type="revolute">
    <origin xyz="0.01054 0 0.1257" rpy="0 0 0" />
    <parent link="Parte1" />
    <child link="Parte2" />
    <axis xyz="0 0 1" />
    <limit lower="-1.5708" upper="1.5708" effort="10" velocity="1.0" />
  </joint>
  <link name="Parte3">
    <inertial>
      <origin xyz="0.068591 0.0022607 0.006097" rpy="0 0 0" />
      <mass value="0.23017" />
      <inertia ixx="0.0001185" ixy="-8.1222E-06" ixz="-4.8088E-06" iyy="0.00064983" iyz="-2.6723E-06" izz="0.00075548" />
    </inertial>
    <visual>
      <origin xyz="0 0 0" rpy="0 0 0" />
      <geometry>
        <mesh filename="package://EnsamblajeFinal.SLDASM/meshes/Parte3.STL" />
      </geometry>
      <material name="">
        <color rgba="0.79216 0.81961 0.93333 1" />
      </material>
    </visual>
    <collision>
      <origin xyz="0 0 0" rpy="0 0 0" />
      <geometry>
        <mesh filename="package://EnsamblajeFinal.SLDASM/meshes/Parte3.STL" />
      </geometry>
    </collision>
  </link>
  <joint name="JointP3" type="revolute">
    <origin xyz="0.15554 -1.5201E-05 0.0087" rpy="0 0 0" />
    <parent link="Parte2" />
    <child link="Parte3" />
    <axis xyz="0 0 1" />
    <limit lower="-1.5708" upper="1.5708" effort="10" velocity="1.0" />
  </joint>
  <link name="Cremallera">
    <inertial>
      <origin xyz="-0.0010073 1.8436E-10 0.0003276" rpy="0 0 0" />
      <mass value="0.059831" />
      <inertia ixx="6.3112E-05" ixy="-9.2972E-14" ixz="-1.4853E-07" iyy="6.2704E-05" iyz="4.593E-14" izz="8.159E-06" />
    </inertial>
    <visual>
      <origin xyz="0 0 0" rpy="0 0 0" />
      <geometry>
        <mesh filename="package://EnsamblajeFinal.SLDASM/meshes/Cremallera.STL" />
      </geometry>
      <material name="">
        <color rgba="0.69412 0.098039 0.098039 1" />
      </material>
    </visual>
    <collision>
      <origin xyz="0 0 0" rpy="0 0 0" />
      <geometry>
        <mesh filename="package://EnsamblajeFinal.SLDASM/meshes/Cremallera.STL" />
      </geometry>
    </collision>
  </link>
  <joint name="JointC" type="prismatic">
    <origin xyz="0.1619 0 0.0041" rpy="0 0 0" />
    <parent link="Parte3" />
    <child link="Cremallera" />
    <axis xyz="0 0 1" />
    <limit lower="-0.054" upper="0" effort="10" velocity="0.1" />
  </joint>
</robot>

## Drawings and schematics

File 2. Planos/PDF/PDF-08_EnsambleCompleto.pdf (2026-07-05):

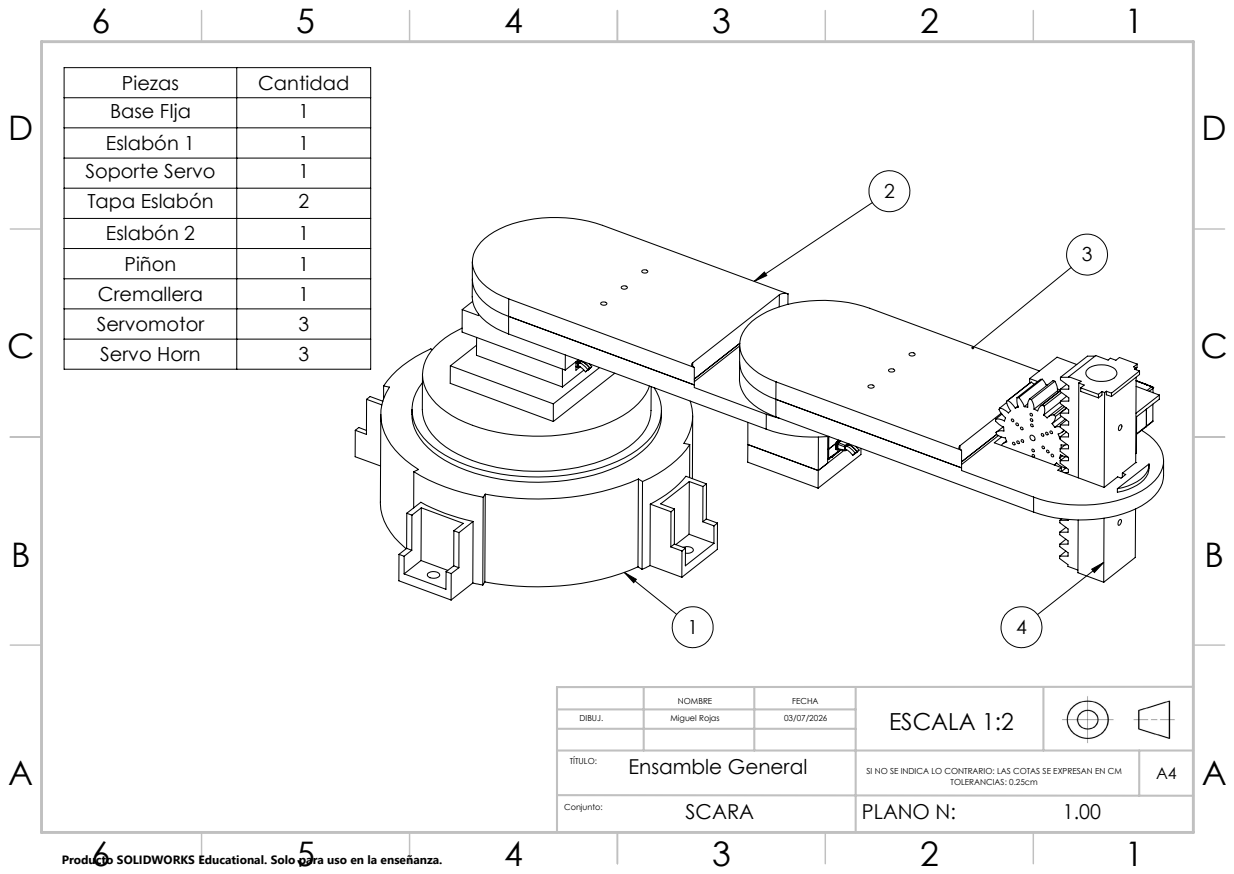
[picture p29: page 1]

Piezas | Cantidad
Base FIja | 1
Eslabón 1 | 1
Soporte Servo | 1
Tapa Eslabón | 2
Eslabón 2 | 1
Piñon | 1
Cremallera | 1
Servomotor | 3
Servo Horn | 3

NOMBRE | FECHA | ESCALA 1:2

DIBUJ. | Miguel Rojas | 03/07/2026

Producto SOLIDWORKS Educational. Solo para uso en la enseñanza.

TÍTULO: Ensamble General | SI NO SE INDICA LO CONTRARIO: LAS COTAS SE EXPRESAN EN CM TOLERANCIAS: 0.25cm | A4

SCARA Conjunto: | PLANO N: 1.00

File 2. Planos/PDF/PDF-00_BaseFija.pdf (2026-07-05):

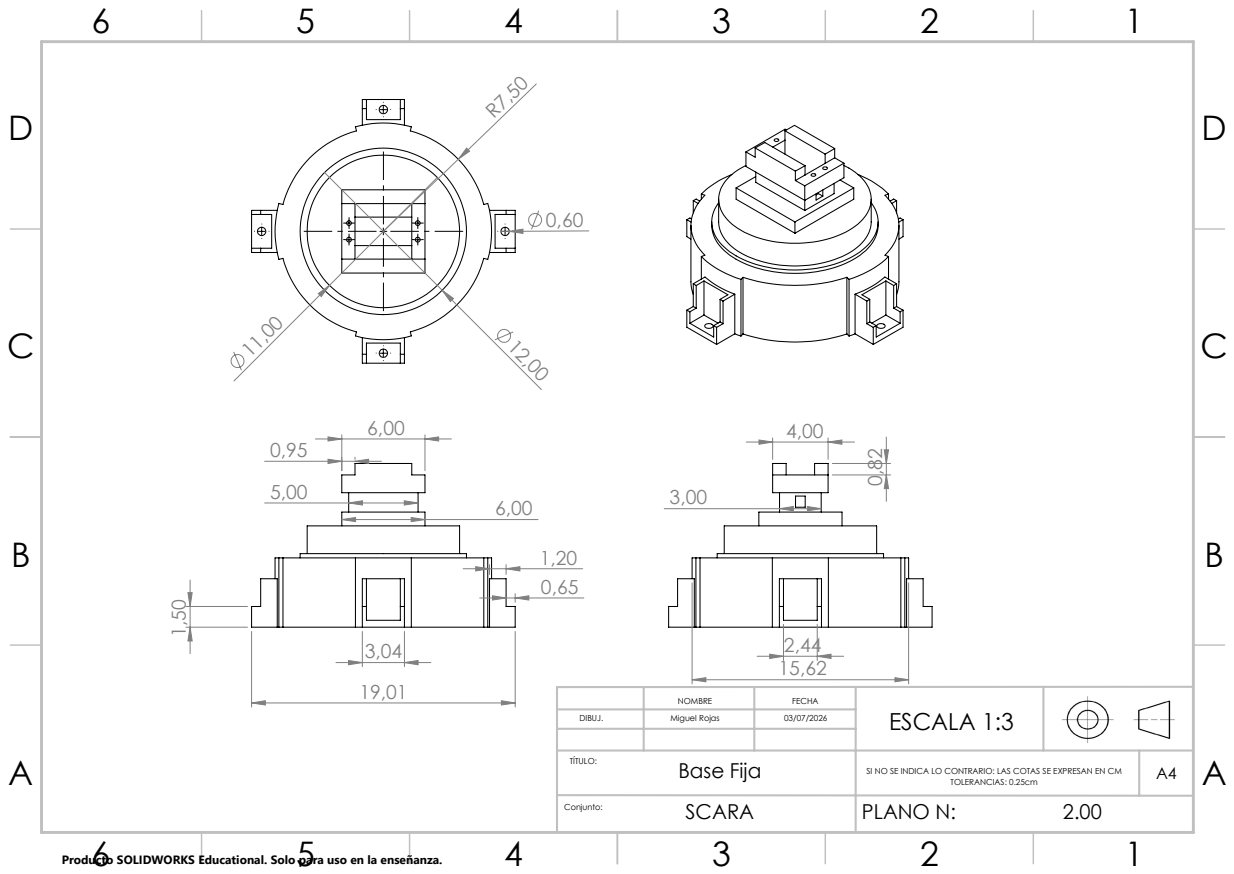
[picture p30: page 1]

NOMBRE | FECHA | ESCALA 1:3

DIBUJ. | Miguel Rojas | 03/07/2026

Producto SOLIDWORKS Educational. Solo para uso en la enseñanza.

TÍTULO: Base Fija | SI NO SE INDICA LO CONTRARIO: LAS COTAS SE EXPRESAN EN CM TOLERANCIAS: 0.25cm | A4

SCARA Conjunto: | PLANO N: 2.00

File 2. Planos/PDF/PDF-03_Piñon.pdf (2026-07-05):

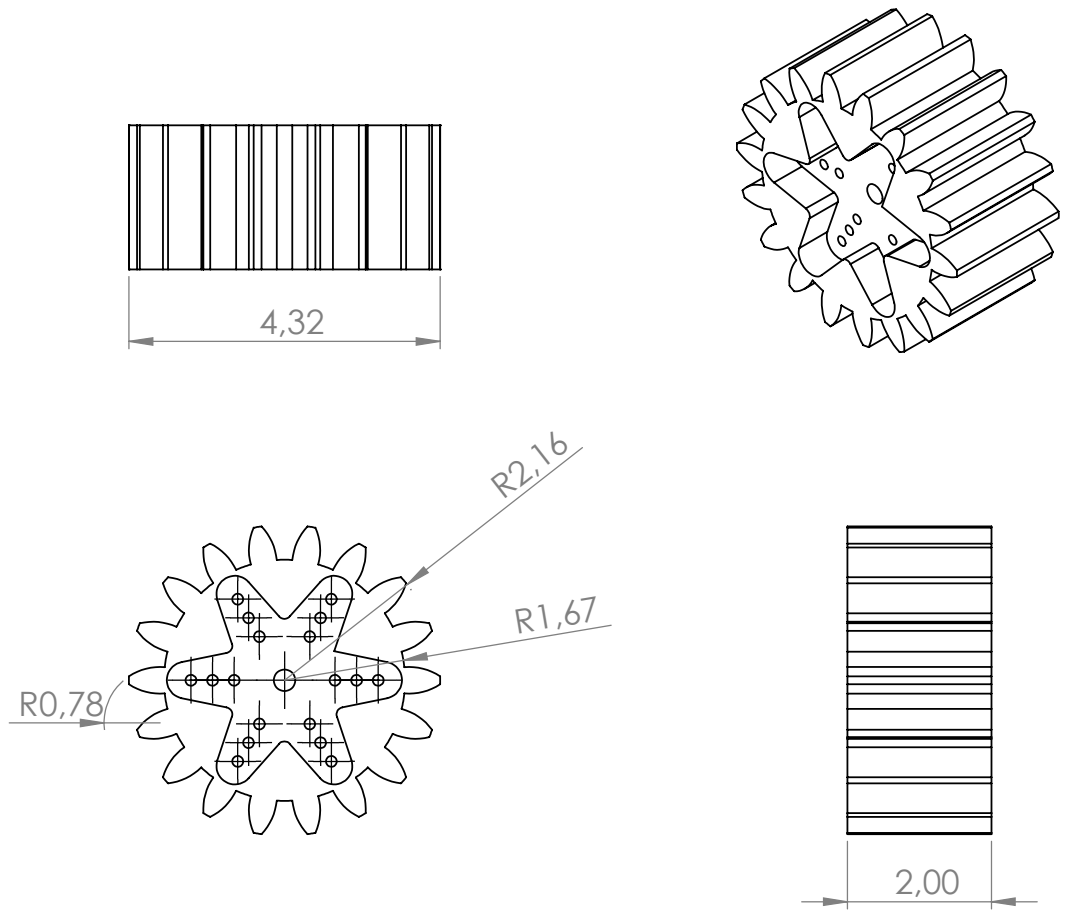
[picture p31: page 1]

NOMBRE | FECHA | ESCALA 1:1

DIBUJ. | Miguel Rojas | 03/07/2026

Producto SOLIDWORKS Educational. Solo para uso en la enseñanza.

TÍTULO: Piñón | SI NO SE INDICA LO CONTRARIO: LAS COTAS SE EXPRESAN EN CM TOLERANCIAS: 0.25cm | A4

SCARA Conjunto: | PLANO N: 7.00

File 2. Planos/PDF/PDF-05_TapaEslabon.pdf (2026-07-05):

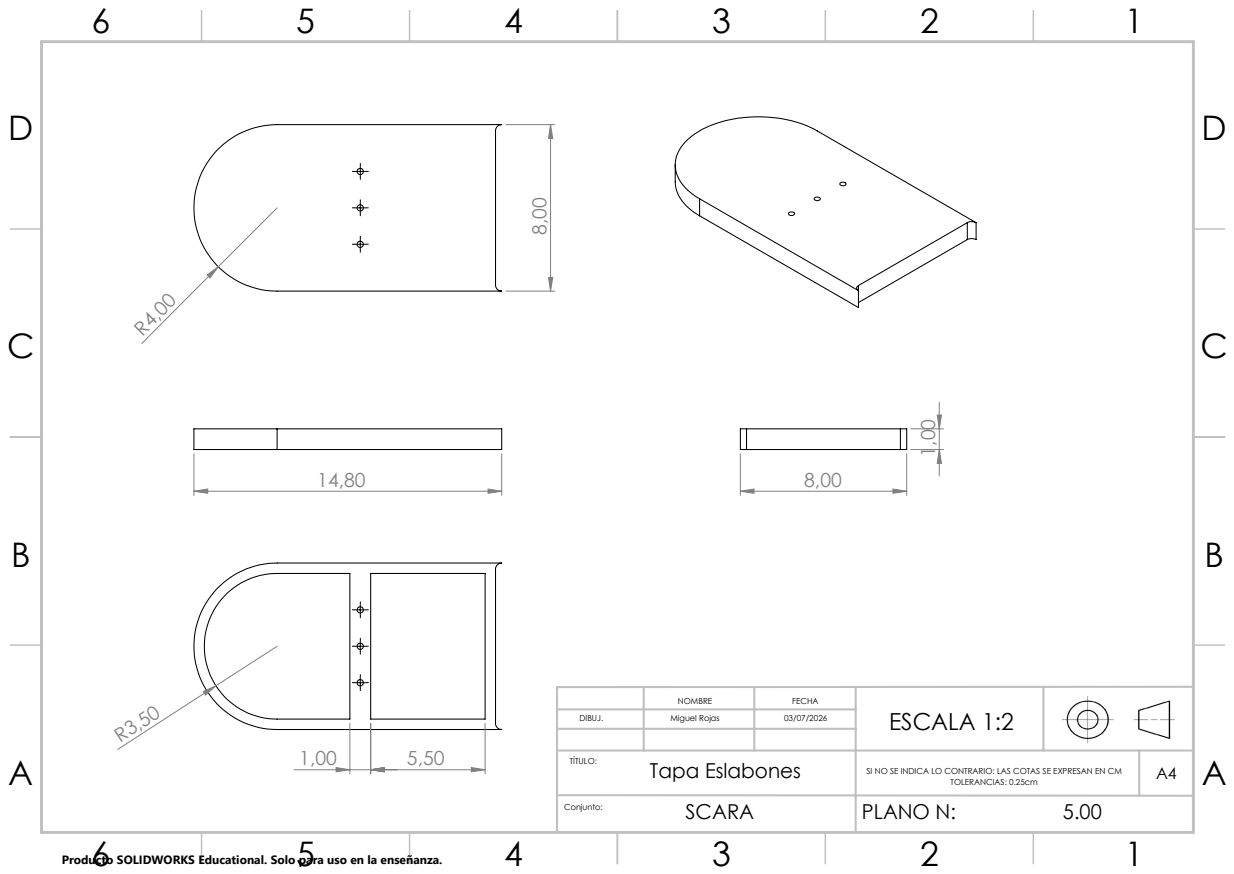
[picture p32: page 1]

Producto SOLIDWORKS Educational. Solo para uso en la enseñanza.

NOMBRE | FECHA | ESCALA 1:2

DIBUJ. | Miguel Rojas | 03/07/2026

TÍTULO: Tapa Eslabones | SI NO SE INDICA LO CONTRARIO: LAS COTAS SE EXPRESAN EN CM TOLERANCIAS: 0.25cm | A4

SCARA Conjunto: | PLANO N: 5.00

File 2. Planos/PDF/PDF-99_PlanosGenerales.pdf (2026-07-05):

2

Piezas | Cantidad


Base FIja | 1
Eslabón 1 | 1
Soporte Servo | 1
Tapa Eslabón | 2
Eslabón 2 | 1
Piñon | 1
Cremallera | 1
Servomotor | 3
Servo Horn | 3

NOMBRE | FECHA | ESCALA 1:2

DIBUJ. | Miguel Rojas | 03/07/2026

TÍTULO: Ensamble General | SI NO SE INDICA LO CONTRARIO: LAS COTAS SE EXPRESAN EN CM TOLERANCIAS: 0.25cm | A4

SCARA Conjunto: | PLANO N: 1.00

Producto SOLIDWORKS Educational. Solo para uso en la enseñanza.

0,60

D | D


NOMBRE | FECHA | ESCALA 1:3

DIBUJ. | Miguel Rojas | 03/07/2026

TÍTULO: Base Fija | SI NO SE INDICA LO CONTRARIO: LAS COTAS SE EXPRESAN EN CM TOLERANCIAS: 0.25cm | A4

SCARA | 2.00

1,00

0,50

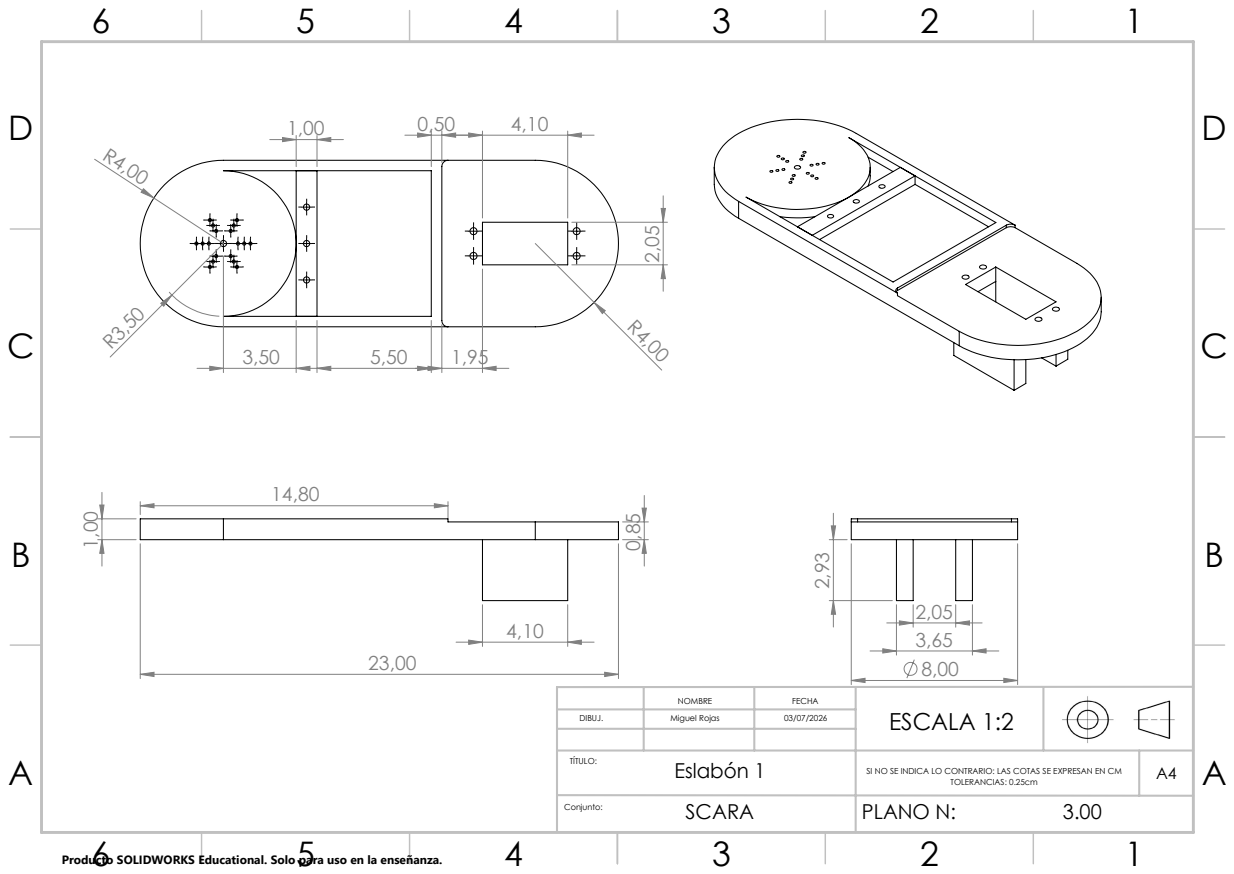
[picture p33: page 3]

NOMBRE | FECHA | ESCALA 1:2

DIBUJ. | Miguel Rojas | 03/07/2026

TÍTULO: Eslabón 1 | SI NO SE INDICA LO CONTRARIO: LAS COTAS SE EXPRESAN EN CM TOLERANCIAS: 0.25cm | A4

SCARA | 3.00

D | D

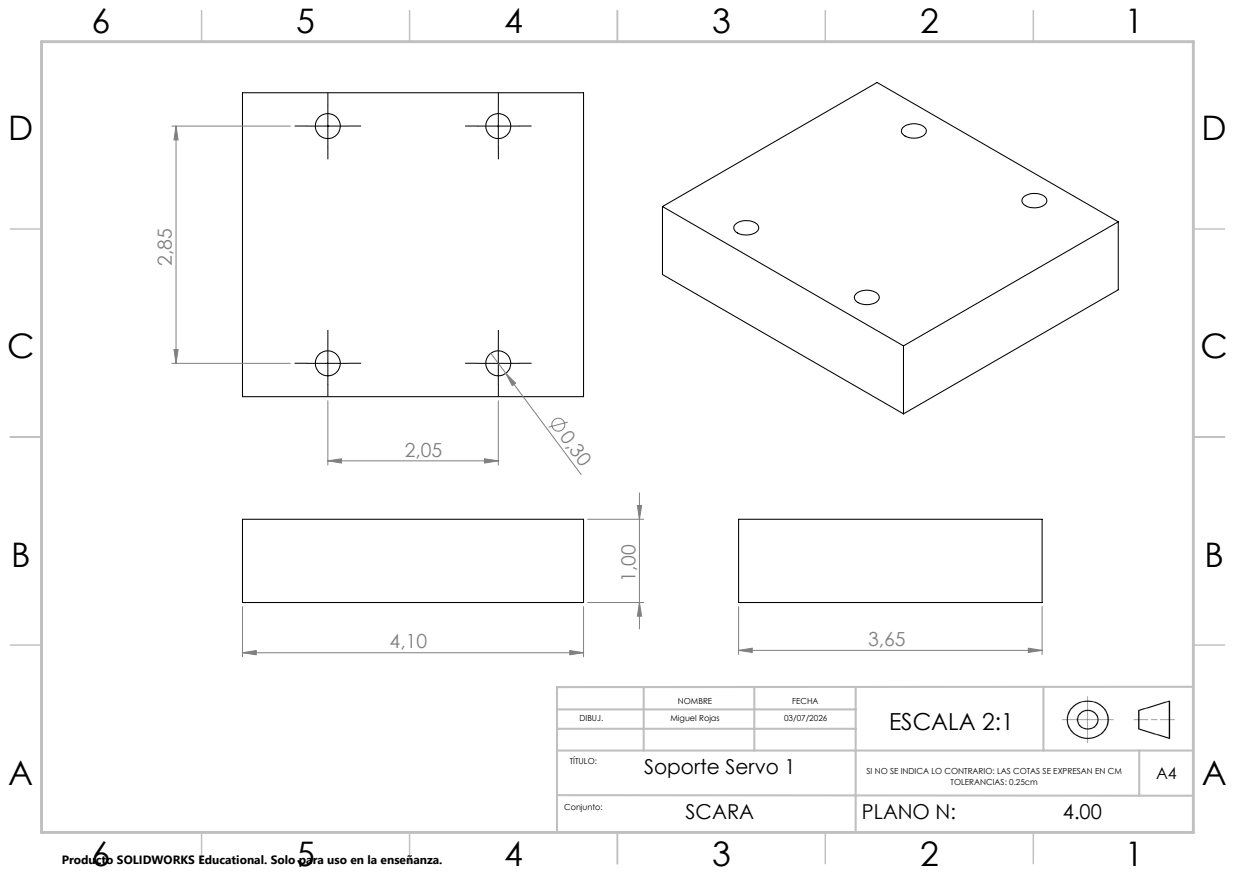
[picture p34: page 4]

NOMBRE | FECHA | ESCALA 2:1

DIBUJ. | Miguel Rojas | 03/07/2026

TÍTULO: Soporte Servo 1 | SI NO SE INDICA LO CONTRARIO: LAS COTAS SE EXPRESAN EN CM TOLERANCIAS: 0.25cm | A4

SCARA | 4.00

D | D


NOMBRE | FECHA | ESCALA 1:2

DIBUJ. | Miguel Rojas | 03/07/2026

TÍTULO: Tapa Eslabones | SI NO SE INDICA LO CONTRARIO: LAS COTAS SE EXPRESAN EN CM TOLERANCIAS: 0.25cm | A4

SCARA | 5.00

5,50

D | D

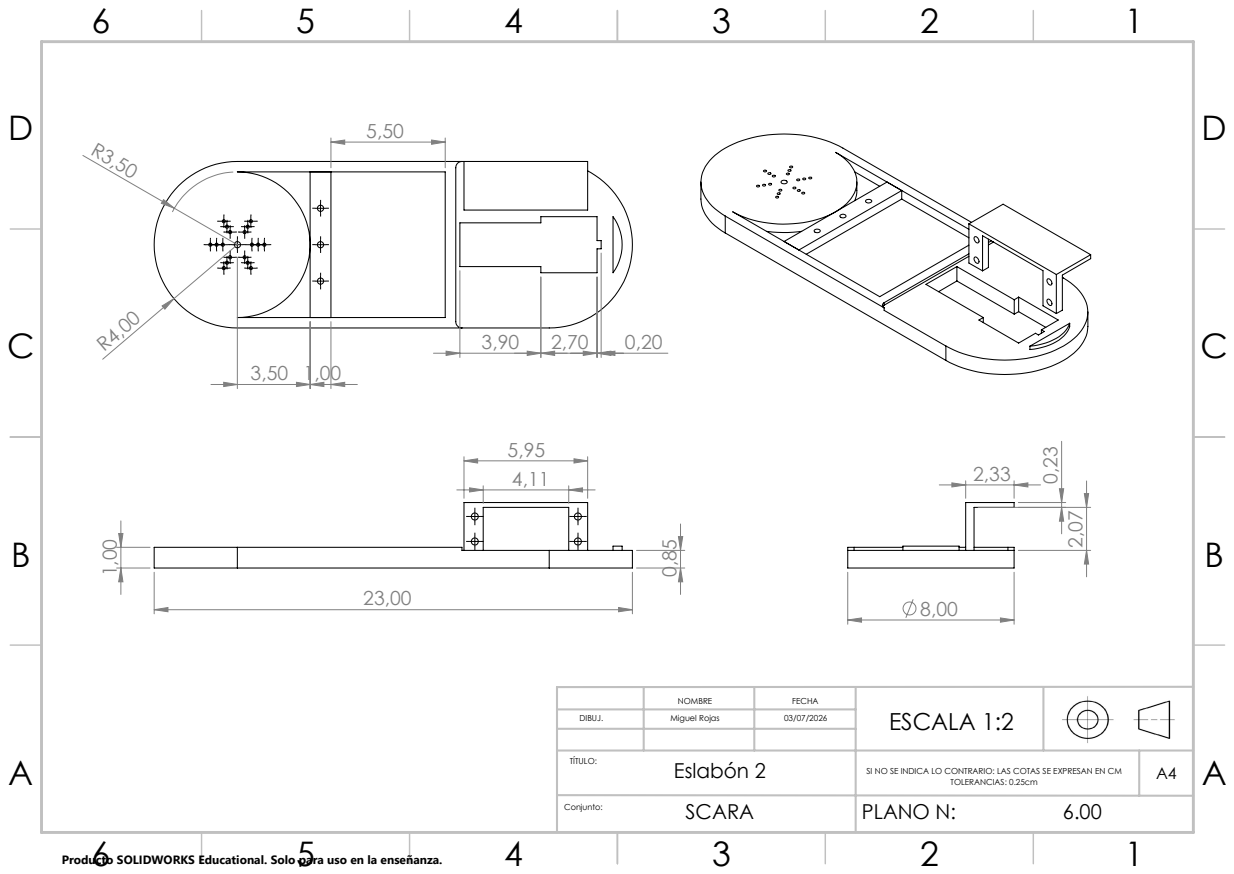
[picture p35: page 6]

NOMBRE | FECHA | ESCALA 1:2

DIBUJ. | Miguel Rojas | 03/07/2026

TÍTULO: Eslabón 2 | SI NO SE INDICA LO CONTRARIO: LAS COTAS SE EXPRESAN EN CM TOLERANCIAS: 0.25cm | A4

SCARA | 6.00

D | D


NOMBRE | FECHA | ESCALA 1:1

DIBUJ. | Miguel Rojas | 03/07/2026

TÍTULO: Piñón | SI NO SE INDICA LO CONTRARIO: LAS COTAS SE EXPRESAN EN CM TOLERANCIAS: 0.25cm | A4

SCARA | 7.00

1,50

0,71

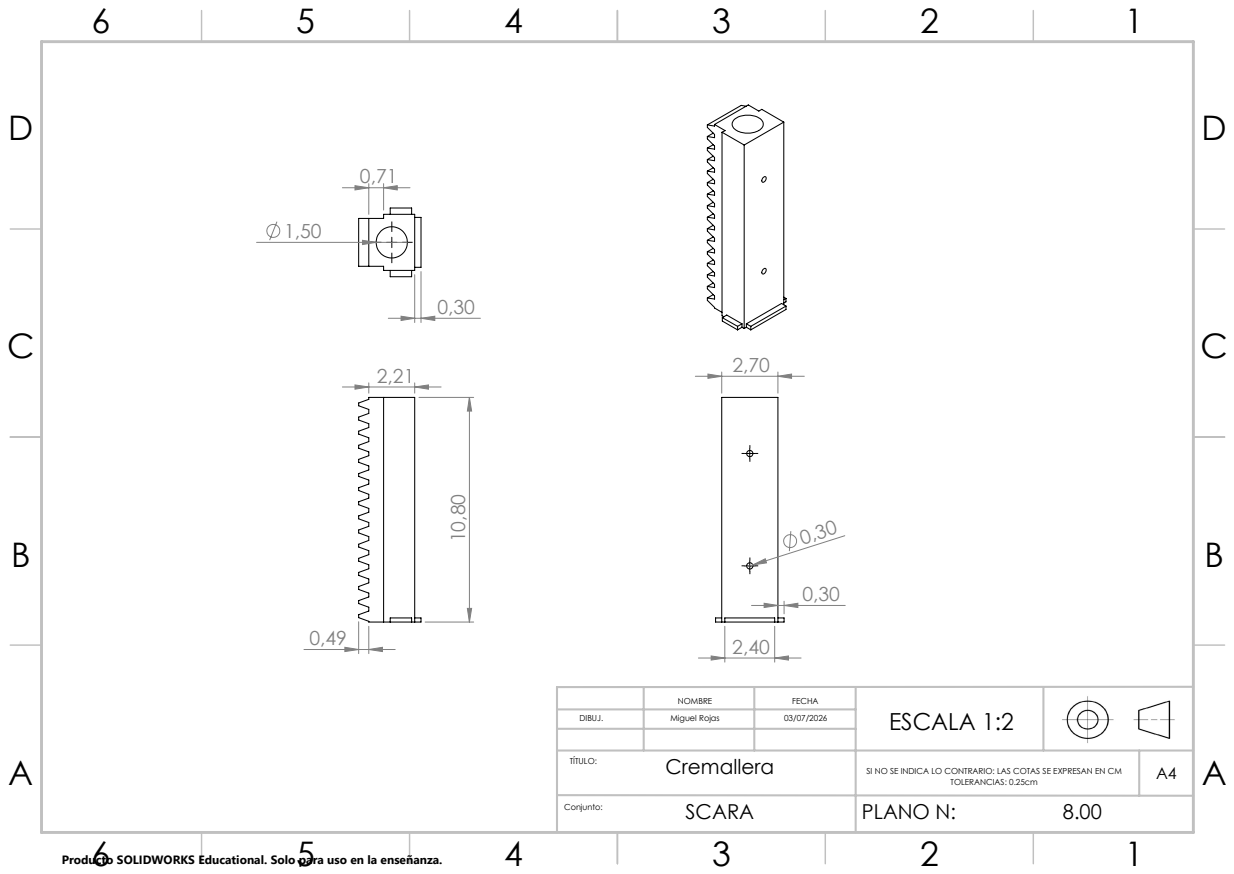
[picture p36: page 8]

NOMBRE | FECHA | ESCALA 1:2

DIBUJ. | Miguel Rojas | 03/07/2026

TÍTULO: Cremallera | SI NO SE INDICA LO CONTRARIO: LAS COTAS SE EXPRESAN EN CM TOLERANCIAS: 0.25cm | A4

SCARA | 8.00

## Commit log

2026-07-04 Organizacion Inicial de Carpetas del Proyecto
2026-07-04 Incorporacion Piezas y Ensambles en SolidWorks
    [CremalleraDesde0.SLDPRT, EnsamblajeFinal.SLDASM, EnsamblajeParte1.SLDASM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]
2026-07-05 Incorporacion Planos de Piezas y Ensambles
    [1-Ensamblaje General.SLDDRW, 2-Base Fija.SLDDRW, 3-Eslabon1.SLDDRW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]
2026-07-09 Incorporacion MATLAB-Simscape
    [CremalleraDesde0_Predeterminado_sldprt.STEP, Parte1_Predeterminado_sldprt.STEP, Parte2_Predeterminado_sldprt.STEP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]
2026-07-09 Estandarizacion de Nomenclatura y agregado README
    [ASM-00_BaseFija_ConServo.SLDASM, ASM-01_Eslabon1_ConServo.SLDASM, ASM-02_Eslabon2_ConServo.SLDASM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]
2026-07-09 Estandarizacion de Nomenclatura en Planos y agregado README
    [PLN-00_BaseFija.SLDDRW, PLN-01_Eslabon1.SLDDRW, PLN-02_Eslabon2.SLDDRW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]
2026-07-22 Incorporacion Modelado Motor DC
2026-07-22 Actualizacion README Modelado Motor DC
2026-08-04 Actualizacion Archivos Matlab-Simscape
    [CremalleraDesde0_Predeterminado_sldprt.STEP, Parte1_Predeterminado_sldprt.STEP, Parte2_Predeterminado_sldprt.STEP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]
2026-10-05 Incorporacion README 06-MATLAB PETER CORKE
    Explicacion paso a paso de la cinematica inversa con el Robotics Toolbox
    (modelos BASETRASL y BASEREVOL), verificacion con fkine e imagenes.
2026-10-05 Incorporacion archivos URDF
    [Cremallera.STL, EnsamblajeFinal.SLDASM.csv, EnsamblajeFinal_SLDASM.urdf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]
2026-10-05 Incorporacion Control Motor (Rele, Asignacion de Polos, Sintonizacion)
    [Analisis5Metodos.xlsx, Sintonizacion_Rele.xlsx]
2026-10-06 Actualizacion README 07-URDF y exportacion URDF (BaseFija / JointCremallera)
    README con el proceso de exportacion desde SolidWorks (SW2URDF), anatomia del
    URDF y relacion con la tabla DH, validacion con PyBullet/yourdfpy. Se reemplaza
    la exportacion del 18-jun por la del 9-jul y se corrigen URDF.py y URDFMOV.py
    (rutas relativas, posicion real del efector).
    [BaseFija.STL, Cremallera.STL, EnsamblajeFinal.SLDASM.csv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]
2026-10-06 Correccion formulas README 06 y 07 (ecuacion fuera de lista, llaves de sistemas)
2026-10-06 Incorporacion README 08-CONTROL MOTOR (literatura, asignacion de polos, rele)
    README general con la planta, la comparacion de los 5 metodos y resultados;
    README de SintonizacionLiteratura (modelo IPD y reglas del Handbook),
    Asignacion_Polos (PI y PID) y Metodo_Rele (36 casos y ranking). Incluye
    imagenes y GraficarFiguras.m para reproducir las figuras.
2026-10-06 Mejora README 08-CONTROL MOTOR: figuras propias y paneles en tabla
    - Se quitan las capturas de los apuntes y las imagenes gigantes del modelo.
    - Caracterizacion, lazo cerrado y mapa de polos generados en GraficarFiguras.m.
    - Paneles de los modelos Simulink recortados en tablas (literatura y rele).
    - Asignacion de polos: ganancias del calculo analitico (Ki = 2.706).
    - Corregidos simbolos raros, formula sin formato y tablas centradas (6, 7 y 8).
2026-10-06 Dejar de versionar archivos generados por Simulink (slprj, slxc) y agregar .gitignore
2026-10-06 Carrera real de la prismatica (0 a 5.4 cm) en los scripts y el README 06
2026-10-06 Comparacion cuantitativa analitico vs Simscape en el README 05
